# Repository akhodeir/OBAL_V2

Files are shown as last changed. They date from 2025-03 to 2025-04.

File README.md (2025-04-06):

# Welcome to the Pi-Fly Wiki

Welcome to the official Pi-Fly github page! 🚀

Pi-Fly is a next-generation automation platform designed to streamline and simplify the configuration of Raspberry Pi-based systems for Ardupilot, Pi Camera, and more. This platform takes advantage of modern Linux capabilities and offers an easy-to-use Python script to automatically configure your system for optimal performance.

Whether you're a developer, hobbyist, or a drone enthusiast, Pi-Fly is designed to help you easily set up and run your systems with minimal effort. Our goal is to provide you with the tools you need to succeed in your projects, whether it's automating flight controllers, working with IMUs, or streaming live video from your Pi Camera.

### Why Pi-Fly?  
- **64-bit Architecture** 🏎️ - Faster and more efficient than previous versions.  
- **Automated Setup** ⚙️ - No manual kernel tweaking; everything is configured via script.  
- **Multi-Sensor Support** 📡 - Works with multiple IMUs, GPS modules, and ADCs.  
- **AI & Computer Vision Ready** 🤖 - With the powerful Raspberry Pi 4, the **Pi Camera Module 3** can be leveraged for AI-based applications such as object detection, autonomous navigation, and real-time video analysis.  
- **Affordable & Open-Source** 💡 - A high-performance alternative to expensive, proprietary flight controllers.  

Feel free to explore the various setup guides, troubleshooting tips, and features that Pi-Fly offers. If you have any questions or suggestions, don't hesitate to reach out—we're here to help you make the most of your experience with Pi-Fly!

Check out the [Pi-Fly Wiki](https://github.com/akhodeir/Pi-Fly/wiki) for all the details.

**Note** : The board/project is not limited to Ardupilot. It can be used with any other flight controller such as PX4, INAV, Betaflight, your own flight controler,...etc
**Note**: : The initial name of the project was OBAL_V2, the name was changed to Pi-Fly due to some political issues with the owner of initial OBAL !!

Happy building! 🚁✨

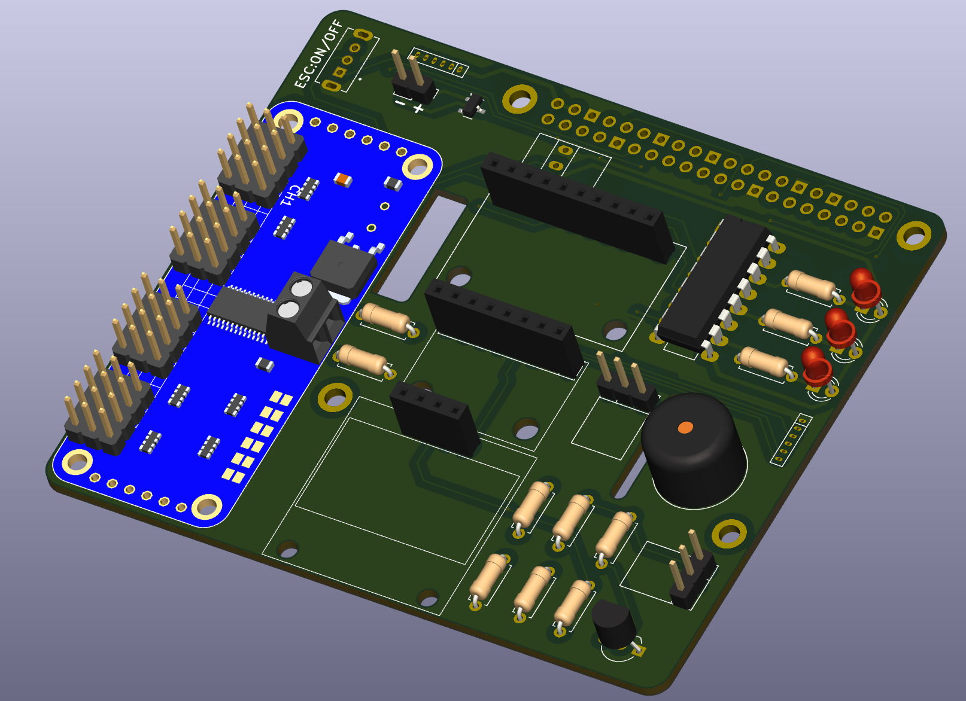
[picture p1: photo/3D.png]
3D PCB


Drone

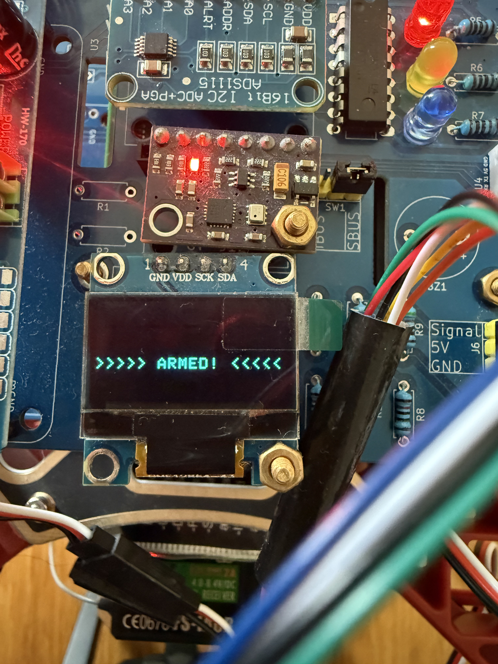
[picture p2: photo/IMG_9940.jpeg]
Armed


# OBAL vs Pi-Fly vs Navio2 - Comparison

## 🚀 Overview
This table outlines the **significant improvements** made from the initial **OBAL** to **Pi-Fly** and compares it with the **Navio2** flight controller system.

---

## ⚙️ **Feature Comparison**

| Feature | OBAL | Pi-Fly | Navio2 |
|---|---|---|---|
| **Linux Kernel** | Bulleyes | Bookworm | Raspbian + ROS |
| **Ardupilot** | 32-bit | 64-bit | ? |
| **Linux Configuration** | Manual | Automatic via script | Manual |
| **Rx Protocol** | PPM/PWM | IBUS and SBUS  | PPM and SBUS |
| **Flight Controller** | Prototype | Complete system| Complete system |
| **IMU** | GY-91 | GY-91, GY-912, ... + more | MPU9250, LSM9DS1 |
| **Display** | No | Yes | No |
| **Power Module** | No | Yes | Yes |
| **License** | Open source | Open source | Proprietary |
| **Price** | < $60 | < $60 | $199 |
| **Link** | [here](https://github.com/HefnySco/OBAL) | [here](#) | [here](https://navio2.hipi.io/) |

---

## ⚠️ **Cons with Initial OBAL:**
- Uses **analog Rx protocol (PPM) or (PWM)**, limiting flexibility.
- Limited to **GY-91 IMU** (only possible IMU).
- **Safety switch** is not well designed.
- No proper **logic conversion** (mix of **5V and 3.3V** logical levels with Raspberry Pi).
- Uses an **old Linux version**, requiring recompilation to disable **`CONFIG_STRICT_DEVMEM`**.
- **32-bit Ardupilot** applications limit performance.

---
## [Donation] Your support is invaluable to this project!

Countless hours of hard work, prototyping, and investment in tools and materials have gone into making this project a reality. If you appreciate the effort and would like to contribute, your donation will help us continue developing and improving Pi-Fly.

Please consider donating for the project. There were tremendous effort added in this project. 
Many prototype boards were built and a lot of tools were purchased to make this project become true.

click image below to start donating :

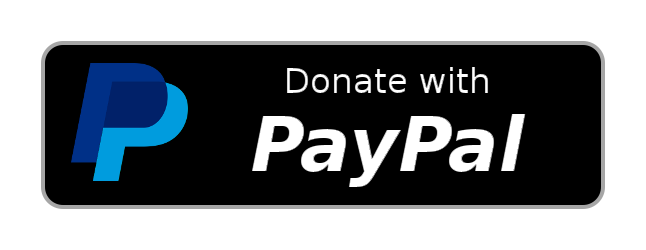
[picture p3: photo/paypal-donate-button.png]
Donate with PayPal (https://www.paypal.com/donate/?hosted_button_id=LGAC3VKW2A8ZA)


**Important**

Use this project at your own risk.

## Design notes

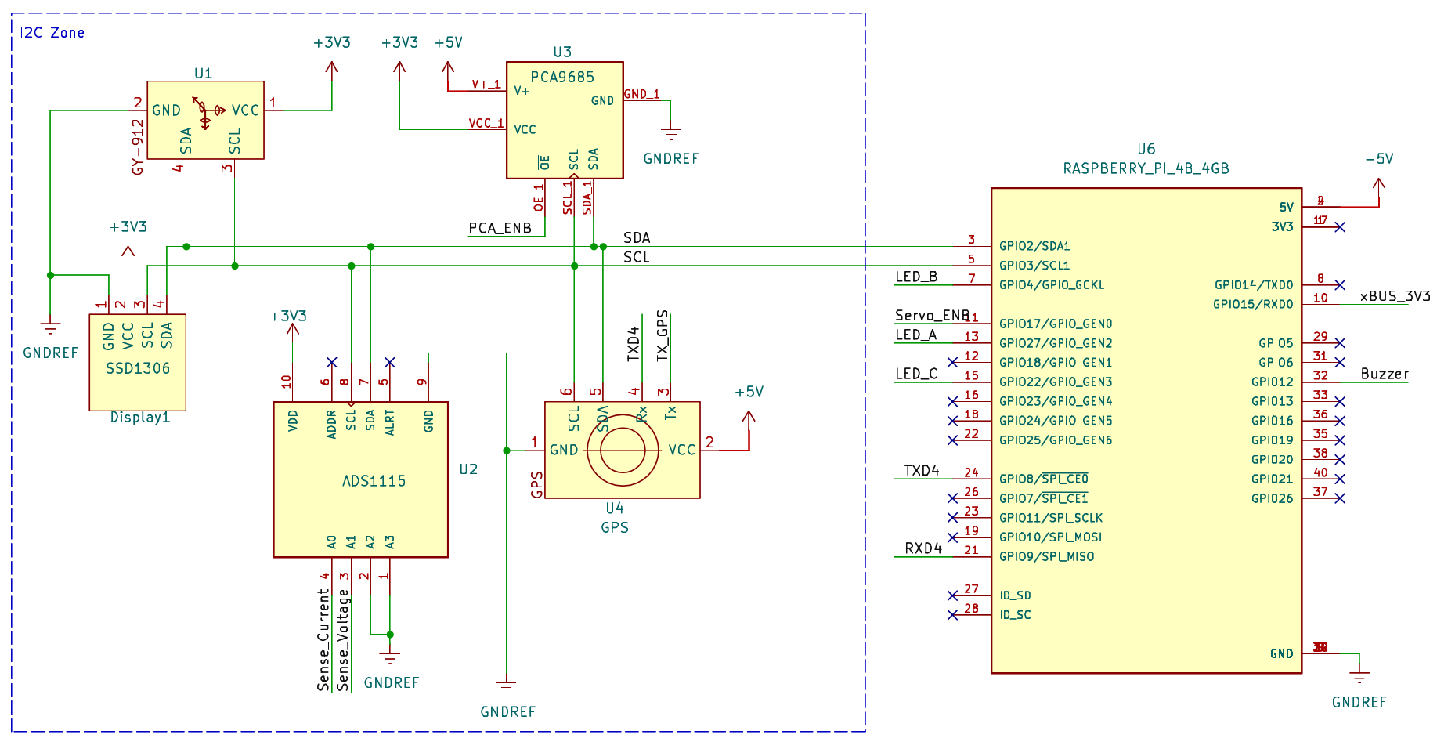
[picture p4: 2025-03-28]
photo/i2c_bus.png

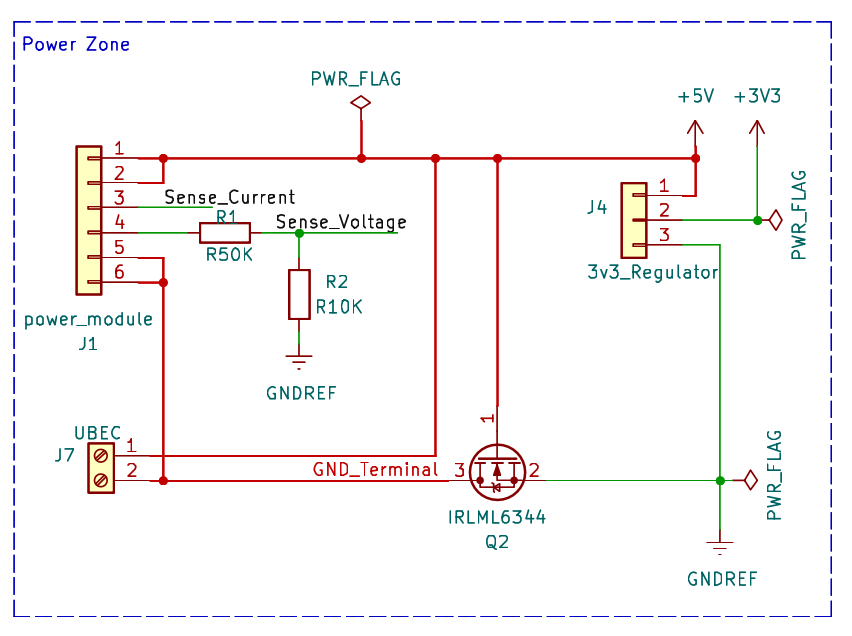
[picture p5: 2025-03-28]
photo/power_zone.png

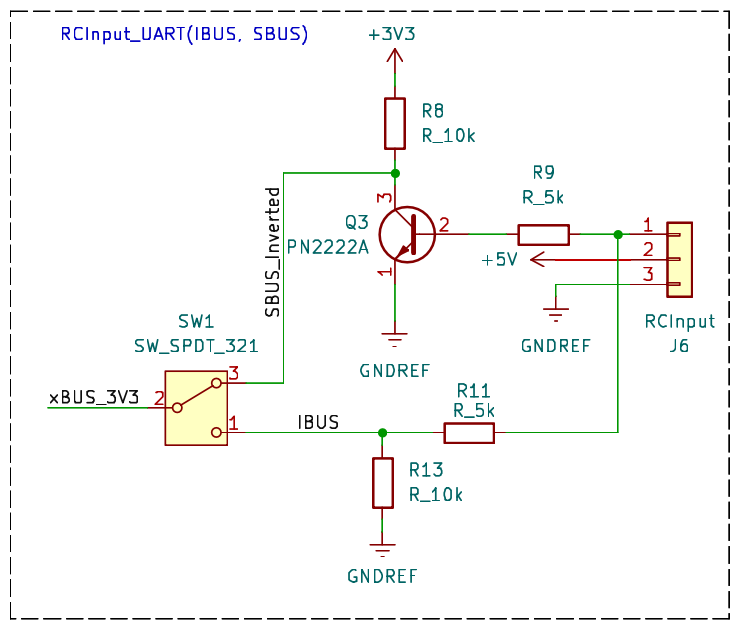
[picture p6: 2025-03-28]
photo/RC_Input.png

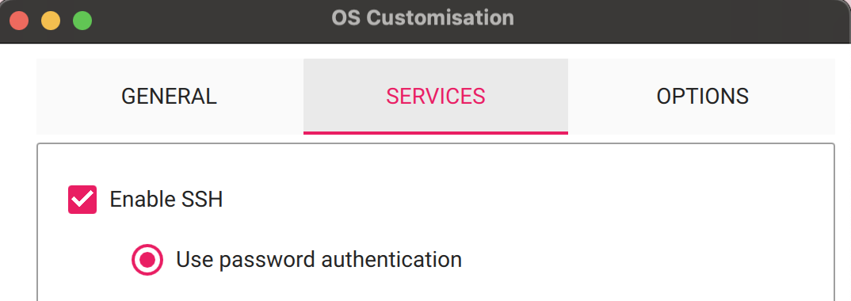
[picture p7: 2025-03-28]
photo/rpi_ssh.png

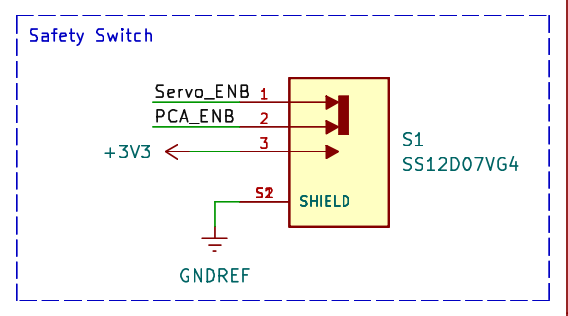
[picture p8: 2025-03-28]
photo/safety_switch.png

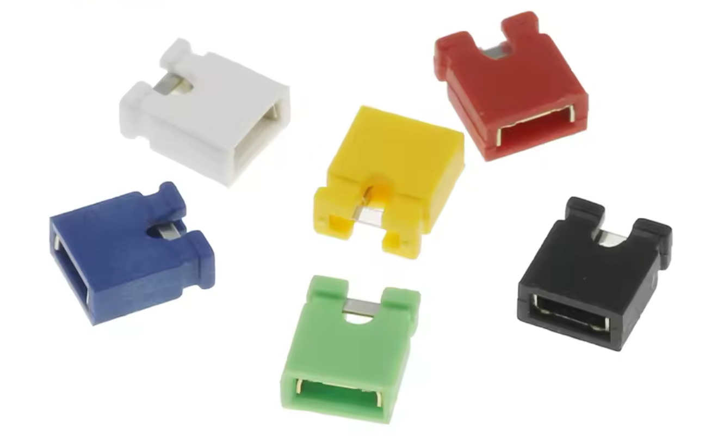
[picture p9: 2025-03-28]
photo/header_jumper.jpg

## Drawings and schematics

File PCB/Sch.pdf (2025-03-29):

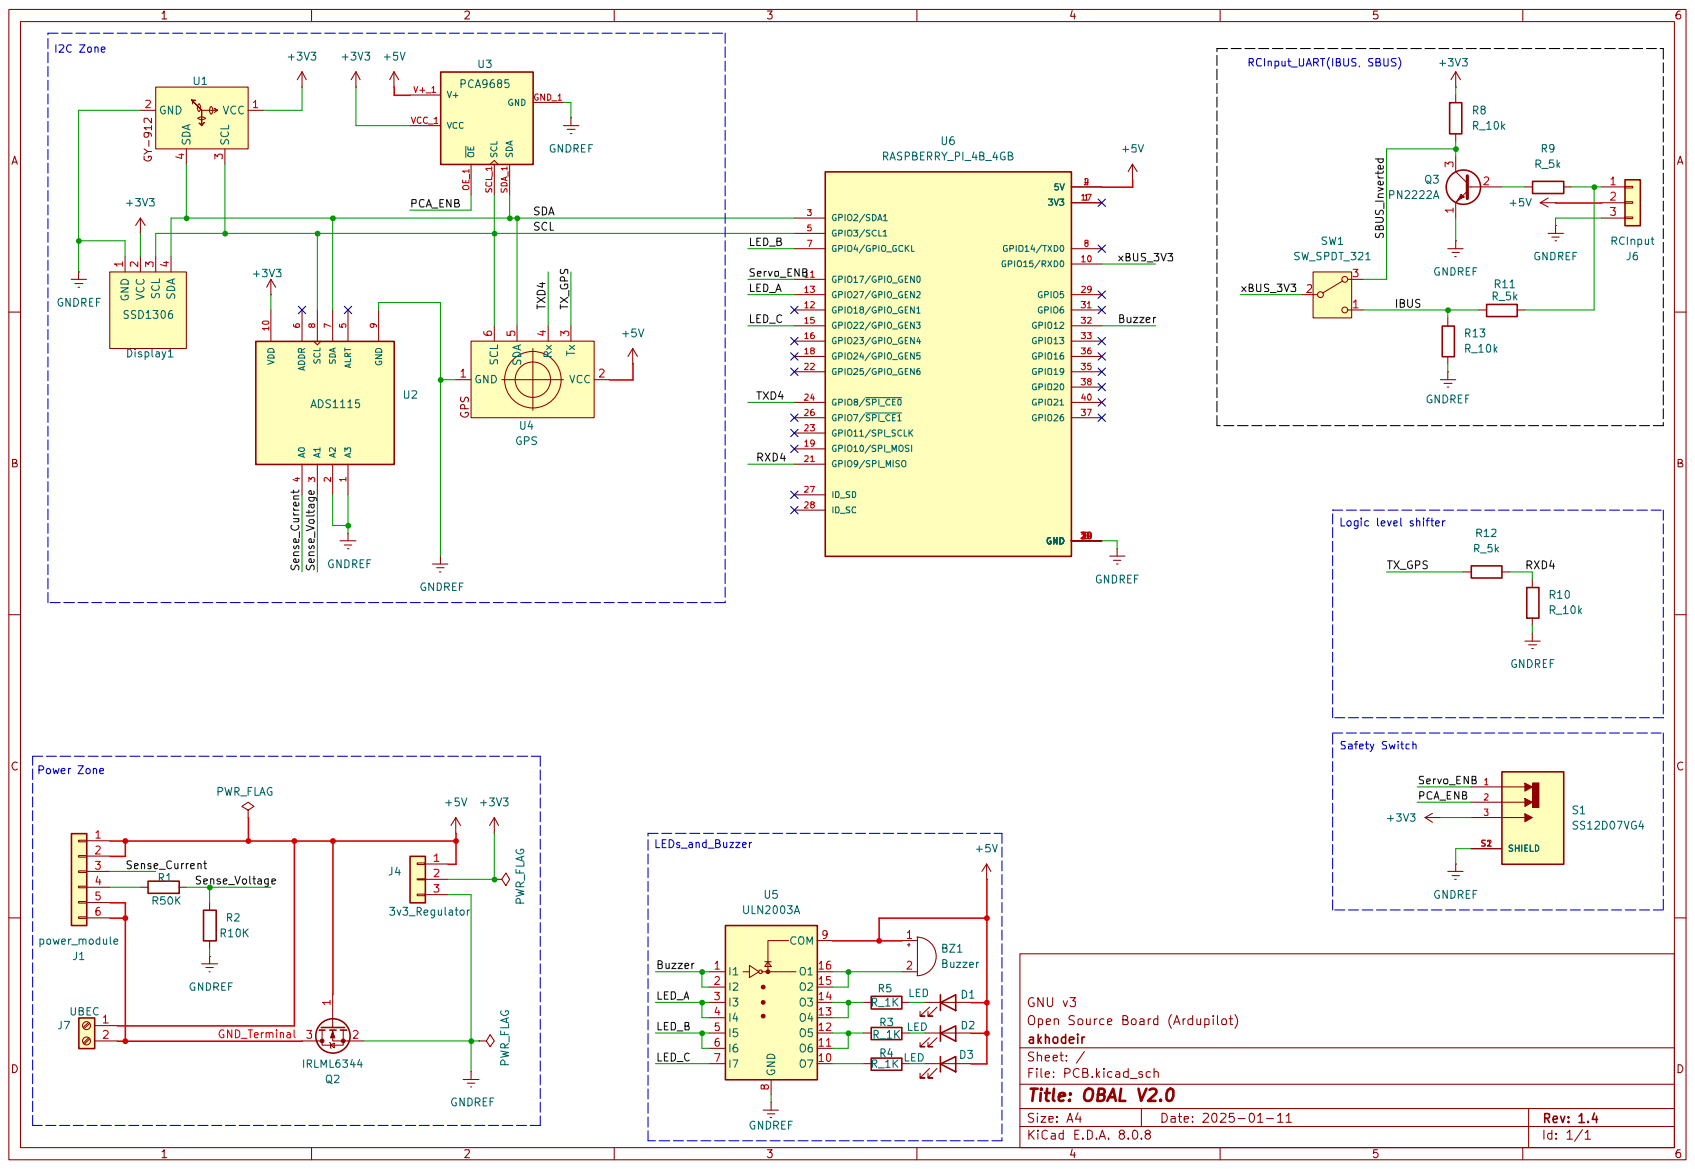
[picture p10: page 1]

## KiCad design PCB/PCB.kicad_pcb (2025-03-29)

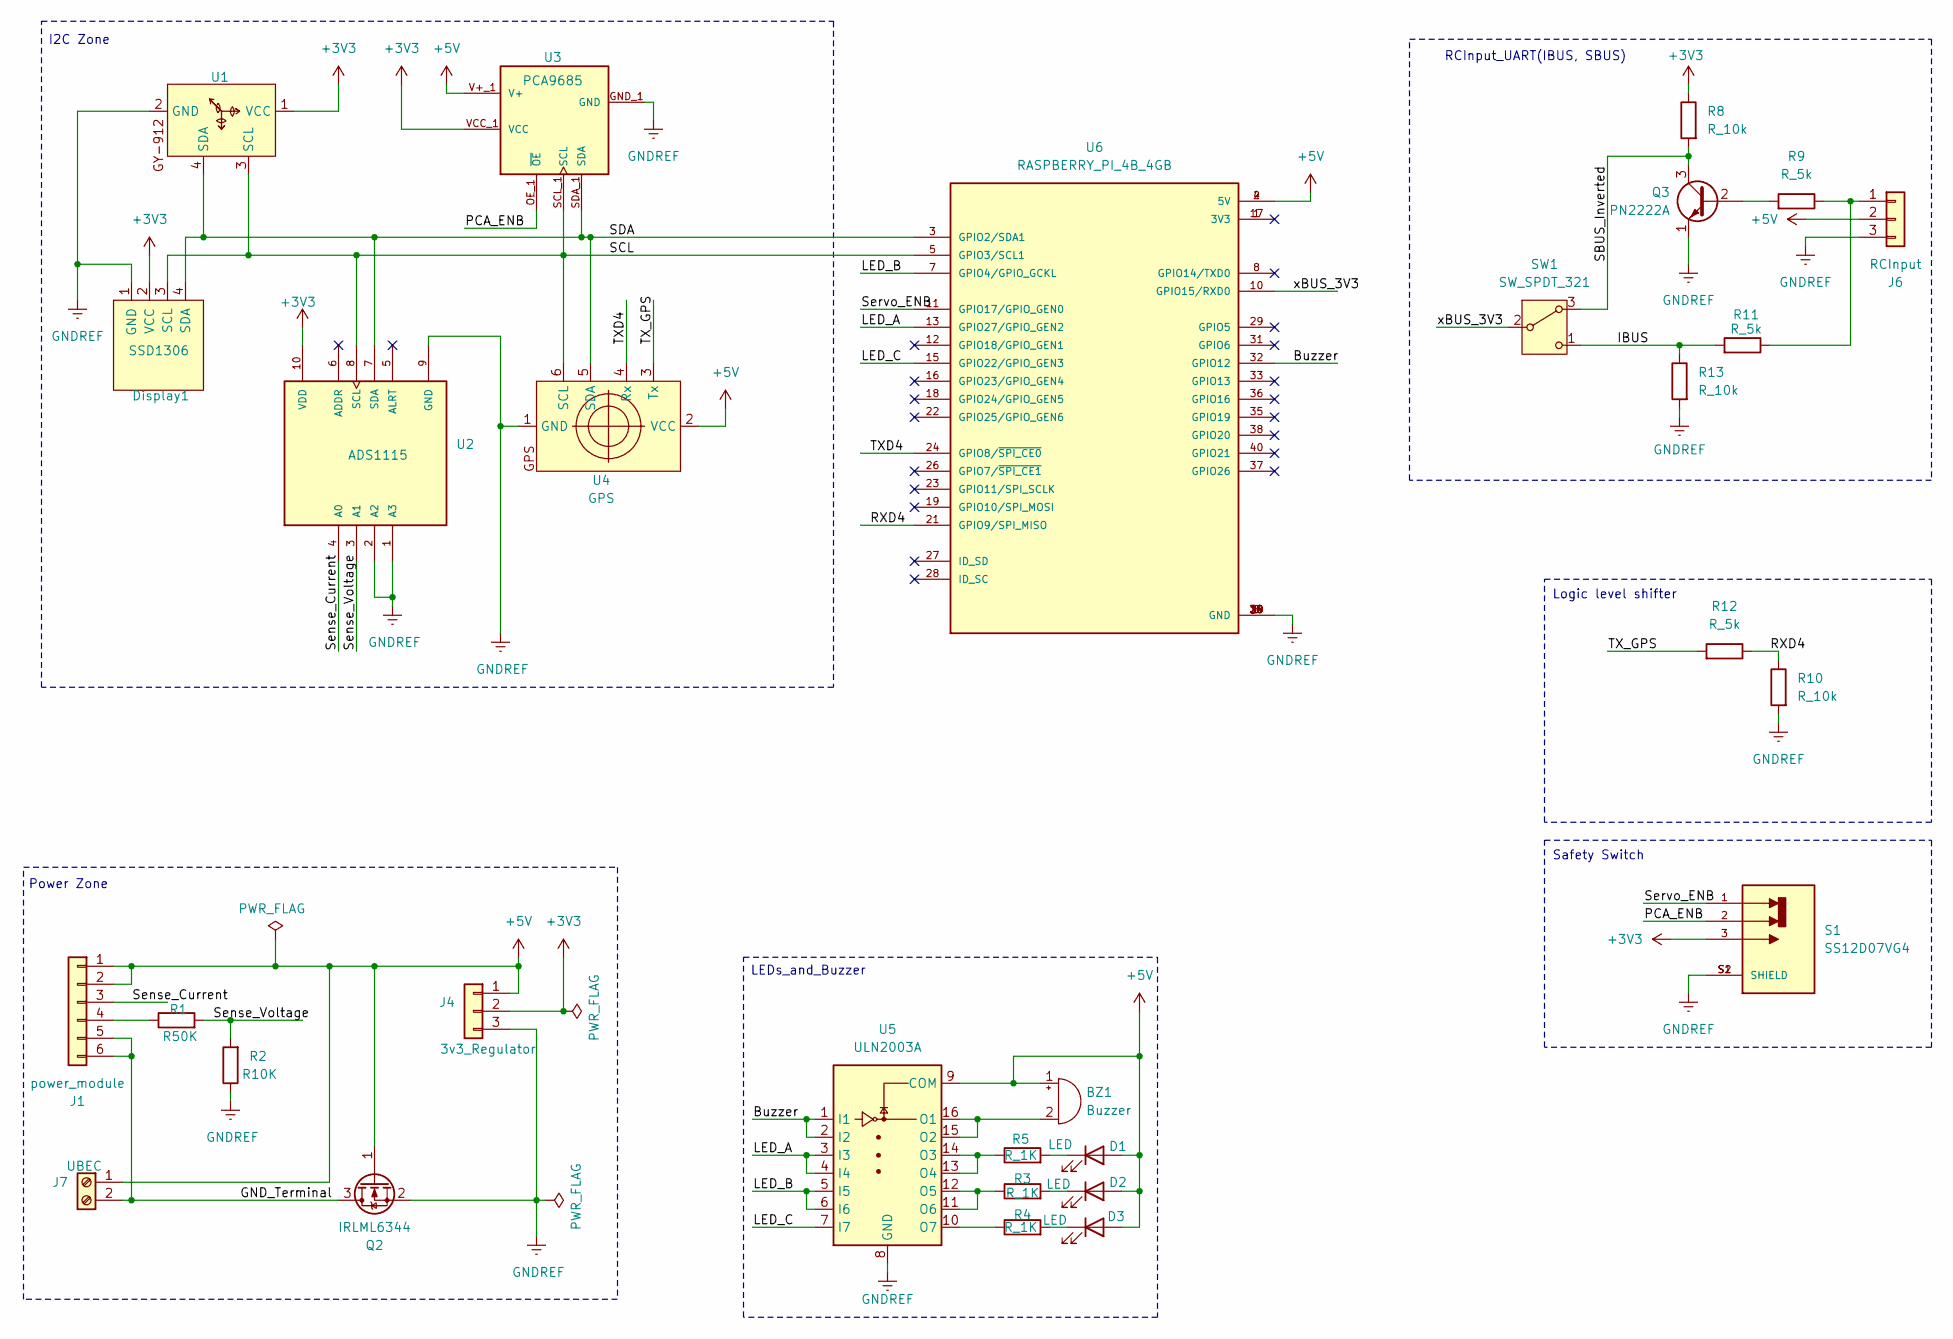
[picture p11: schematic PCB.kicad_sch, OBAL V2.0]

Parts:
BZ1: Buzzer; Buzzer_12x9.5RM7.6
D1, D2, D3: LED; LED_D3.0mm
Display1: SSD1306
J1: power_module
J4: 3v3_Regulator; Regulator
J6: RCInput; RCInput_xBUS
J7: UBEC; PinHeader_1x02_P2.54mm_Vertical
Q2: IRLML6344; SOT-23
Q3: PN2222A; TO-92_Inline_Wide
R1: R50K; R_Axial_DIN0207_L6.3mm_D2.5mm_P7.62mm_Horizontal
R2: R10K; R_Axial_DIN0207_L6.3mm_D2.5mm_P7.62mm_Horizontal
R3, R4, R5: R_1K; R_Axial_DIN0207_L6.3mm_D2.5mm_P7.62mm_Horizontal
R8, R10, R13: R_10k; R_Axial_DIN0207_L6.3mm_D2.5mm_P7.62mm_Horizontal
R9, R11, R12: R_5k; R_Axial_DIN0207_L6.3mm_D2.5mm_P7.62mm_Horizontal
S1: SS12D07VG4; SW_SS12D07VG4; PARTREV 1
SW1: SW_SPDT_321; xBUS_Selector
U1: GY-912
U2: ADS1115; MODULE_ADS1115; PARTREV N/A
U3: PCA9685; MODULE_815; PARTREV C
U4: GPS; GPS_SH1.0
U5: ULN2003A; DIP-16_W7.62mm_LongPads
U6: RASPBERRY_PI_4B_4GB; RPI_4_Hat_B+; PARTREV 4

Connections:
+3V3: Display1.2 (VCC), J4.2, R8.1, S1.3, U1.1 (VCC), U2.10 (VDD), U3.VCC_1 (VCC)
+5V: BZ1.1 (+), D1.2 (A), D2.2 (A), D3.2 (A), J1.1, J1.2, J4.1, J6.2, J7.1, Q2.1 (G), U3.V+_1 (V+), U4.2 (VCC), U5.9 (COM), U6.2 (5V), U6.4 (5V)
/Buzzer: U5.1 (I1), U5.2 (I2), U6.32 (GPIO12)
/GND_Terminal: J1.5, J1.6, J7.2, Q2.3 (S)
/IBUS: R11.2, R13.1, SW1.1 (C)
/LED_A: U5.3 (I3), U5.4 (I4), U6.13 (GPIO27/GPIO_GEN2)
/LED_B: U5.5 (I5), U5.6 (I6), U6.7 (GPIO4/GPIO_GCKL)
/LED_C: U5.7 (I7), U6.15 (GPIO22/GPIO_GEN3)
/PCA_ENB: S1.2, U3.OE_1 (~OE)
/RXD4: R10.1, R12.1, U6.21 (GPIO9/SPI_MISO)
/SBUS_Inverted: Q3.3 (C), R8.2, SW1.3 (A)
/SCL: Display1.3 (SCL), U1.3 (SCL), U2.8 (SCL), U3.SCL_1 (SCL), U4.6 (SCL), U6.5 (GPIO3/SCL1)
/SDA: Display1.4 (SDA), U1.4 (SDA), U2.7 (SDA), U3.SDA_1 (SDA), U4.5 (SDA), U6.3 (GPIO2/SDA1)
/Sense_Current: J1.3, U2.4 (A0)
/Sense_Voltage: R1.2, R2.2, U2.3 (A1)
/Servo_ENB: S1.1, U6.11 (GPIO17/GPIO_GEN0)
/TXD4: U4.4 (Rx), U6.24 (GPIO8/~SPI_CE0)
/TX_GPS: R12.2, U4.3 (Tx)
/xBUS_3V3: SW1.2 (B), U6.10 (GPIO15/RXD0)
GNDREF: Display1.1 (GND), J4.3, J6.3, Q2.2 (D), Q3.1 (E), R2.1, R10.2, R13.2, S1.S1 (SHIELD), S1.S2 (SHIELD), U1.2 (GND), U2.1 (A3), U2.2 (A2), U2.9 (GND), U3.GND_1 (GND), U4.1 (GND), U5.8 (GND), U6.6 (GND), U6.9 (GND), U6.14 (GND), U6.20 (GND), U6.25 (GND), U6.30 (GND), U6.34 (GND), U6.39 (GND)
unnamed: BZ1.2 (-), U5.15 (O2), U5.16 (O1)
unnamed: D1.1 (K), R5.2
unnamed: D2.1 (K), R3.2
unnamed: D3.1 (K), R4.2
unnamed: J1.4, R1.1
unnamed: J6.1, R9.1, R11.1
unnamed: Q3.2 (B), R9.2
unnamed: R5.1, U5.13 (O4), U5.14 (O3)
unnamed: R3.1, U5.11 (O6), U5.12 (O5)
unnamed: R4.1, U5.10 (O7)

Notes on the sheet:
I2C Zone
Power Zone
LEDs_and_Buzzer
Safety Switch
Logic level shifter
RCInput_UART(IBUS, SBUS)

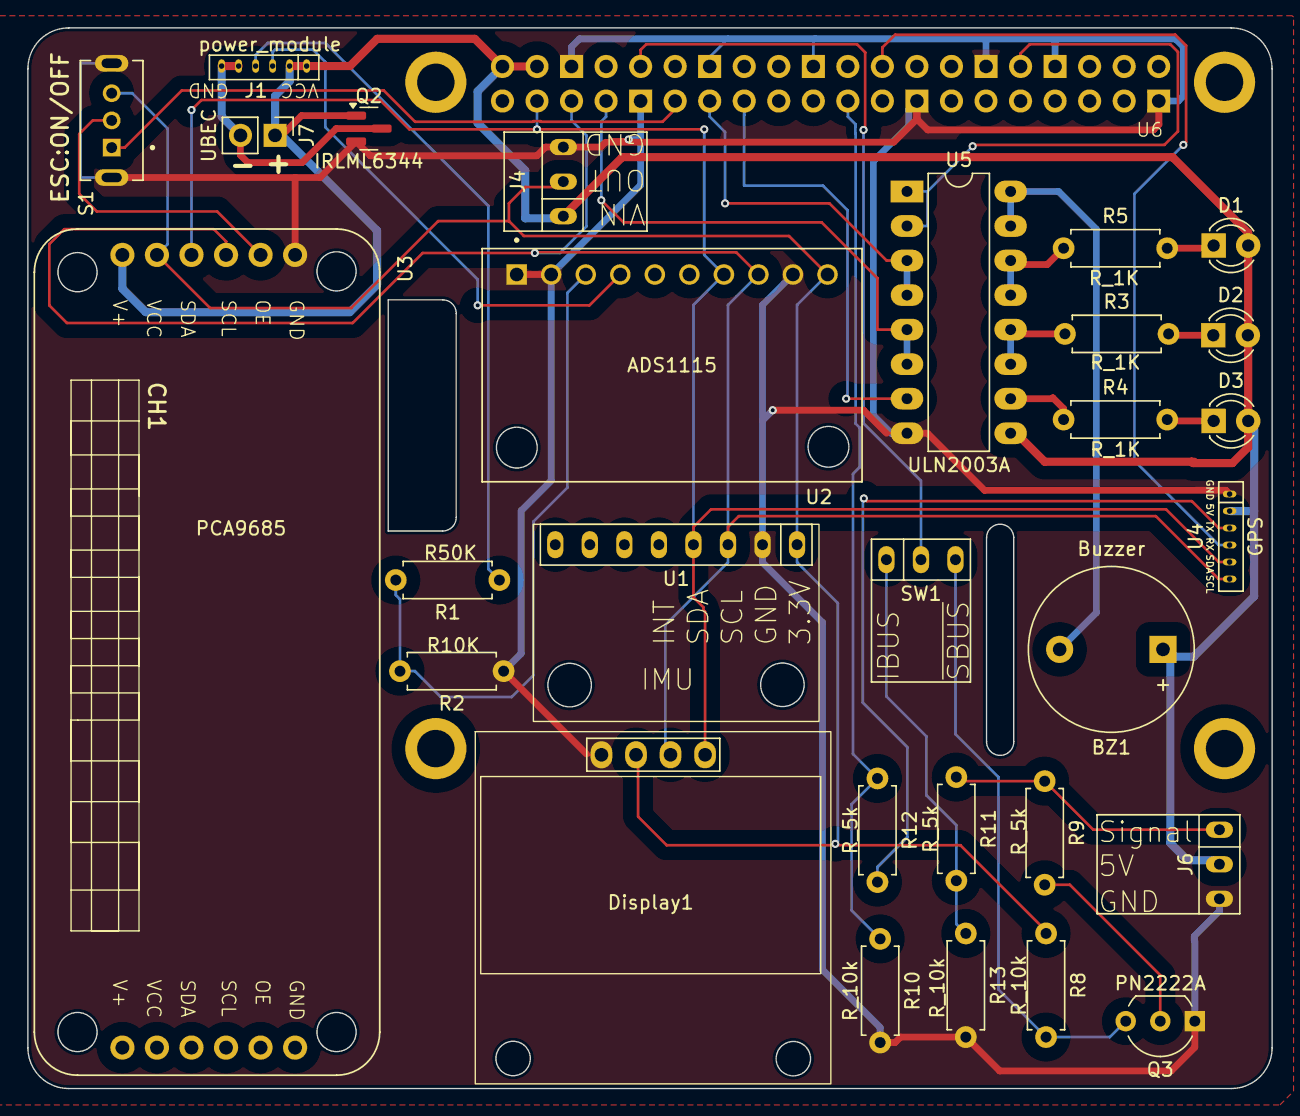
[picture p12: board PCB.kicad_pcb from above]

Board: 2 copper layers, 91.5 x 78.0 mm, 30 parts (0 on the bottom side), 30 nets.

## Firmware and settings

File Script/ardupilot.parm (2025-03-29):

SYSID_THISMAV 1
FRAME_CLASS 1
FRAME_TYPE  1

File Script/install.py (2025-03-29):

import os
import sys
import getopt

def add_service(serviceFilePath, serviceFileContent):
    fileExist = False
    serviceName = serviceFilePath.split('/')[-1]
    if os.path.exists(serviceFilePath):
        fileExist = True
        print(f'stop existing service : {serviceName}')
        os.system(f'sudo systemctl stop {serviceName}')

    with open(serviceFilePath, 'w') as file:
        file.write(serviceFileContent)

    print(f'enable service : {serviceName}')
    os.system(f'sudo systemctl enable {serviceName}')
    print(f'start service : {serviceName}')
    os.system(f'systemctl daemon-reload')
    os.system(f'sudo systemctl start {serviceName}')
    
def disable_bt():
	os.system('sudo systemctl disable hciuart')
	os.system('sudo systemctl stop hciuart')
	

#cpuinfo = os.system('cat /proc/cpuinfo')
#cpuinfo = os.system('cat /proc/device-tree/model')
cpuinfo = os.popen('cat /sys/firmware/devicetree/base/model').read()
arch = os.popen('uname -m').read()

print(cpuinfo)
if ('Raspberry Pi 4' not in cpuinfo) or ('aarch64' not in arch):
    print('This script is only for Raspberry Pi 4 (x64)')
    sys.exit(2)


argv = sys.argv[1:]
print('Number of arguments : ' , len(argv))
for arg in argv:
    print("provided arguments : ", arg)

#default values 
ip = ''
app = ''
#both parameters shall exist
if len(argv) != 2 :
    print('please enter ip and application name to the scipt')
    sys.exit(2)

# parse command line options:
try:
    opts, args = getopt.getopt(argv,'x',['ip=','app='])
    print('The existing options are : ', opts)
except getopt.GetoptError:
    print('python3 install.py --ip=192.168.178.20 --app=arducopter')
    sys.exit(2)

for opt, arg in opts:
    if opt in ("-i", "--ip"):
        #ip address for the machine that has mission planner
        ip = arg
    elif opt in ("-a", "--app"):
        #name of the application (arducopter,arduplane,..etc)
        app  = arg.lower()

APPS = ['arducopter','arduplane','rover',]


#check if the user selected an app from the list and this app exists in current folder
if (app not in APPS) or (not os.path.exists(app)) or (ip == '') or (app == ''):
    sys.exit(2)

cwd = os.getcwd() + '/'

appPath = cwd + app


paramFile= 'ardupilot.parm'
paramFileContent = '''
SYSID_THISMAV 1
FRAME_CLASS 1
FRAME_TYPE  1
'''

if app == 'arducopter':
    with open(paramFile, 'w') as file:
        file.write(paramFileContent)

#service file path
serviceFilePath = '/lib/systemd/system/ardupilot.service'
#service file content
serviceFileContent =f'''
[Unit]
Description=Autopilot service
After=systemd-modules-load.service

[Service]
Type=simple
ExecStart={appPath} --serial0 udp:{ip}:14550:bcast --serial4 /dev/ttyAMA4
Restart=on-failure
CPUAffinity=3
IOSchedulingClass=real-time
IOSchedulingPriority=0
LimitNICE=-10

[Install]
WantedBy=multi-user.target
'''

add_service(serviceFilePath, serviceFileContent)

#service file path
serviceFilePath = '/lib/systemd/system/picamera.service'
#service file content
serviceFileContent =f'''
[Unit]
Description=Run Pi Camera as Webcam
After=network.target

[Service]
Type=simple
Restart=on-failure
ExecStart=/bin/sh -c "rpicam-vid -n --width 1280 --height 720 -b 1000000 --framerate 15 -t 0 -o - | gst-launch-1.0 -v fdsrc ! h264parse ! rtph264pay config-interval=10 pt=96 ! udpsink host={ip} port=9000"
CPUAffinity=2
Restart=on-failure

[Install]
WantedBy=default.target
'''

add_service(serviceFilePath, serviceFileContent)

print('Disable Bluetooth')
disable_bt()

configFile = '/boot/firmware/config.txt'

lines = [
	'dtparam=i2c_arm=on', #Enable I2C
	'dtparam=i2c_arm_baudrate=400000', #enable I2C speed
	'dtparam=spi=on', #Enable SPI
	'enable_uart=1', #Enable UART
	'dtoverlay=uart4', #Enable UART4 on GPIO 8, 9
]

with open(configFile) as f:
    datafile = f.readlines()
    for l in datafile:
        l = l[0:-1] #remove new line from l 
        if l in lines:
            print(f"found in {configFile} : ", l)
            #remove found lines from list of lines to be appended
            lines.remove(l) 
            

with open(configFile,'+a') as f:
    for l in lines:
        f.write(l+'\n')
        

file = '/boot/firmware/cmdline.txt'

print('remove the console serial prints')
os.system(f'sed -i -e "s/console=serial0,115200//g" {file}')
os.system(f"sudo grep -qxF 'isolcpus' {file} || sed -i 's/$/ isolcpus=2,3/' {file}")

#load the i2c dev to the modules at startup
#or user must use "sudo modprobe i2c-dev" for each boot-up
file = '/etc/modules'
os.system(f'sudo chmod 777 {file}')
os.system(f'sudo grep -qxF "i2c-dev" {file} || echo "i2c-dev" >> {file}')

print("please restart your PI : sudo reboot now")
